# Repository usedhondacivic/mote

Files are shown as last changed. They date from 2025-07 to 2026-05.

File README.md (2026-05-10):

# Mote





A low cost and high confidence mobile robot.

## Motivation

Robotics is more fun with real hardware.

["Low cost"](https://www.robotshop.com/products/clearpath-robotics-turtlebot-4-mobile-robot) robots are prohibitively expensive for aspiring engineers.
We believe robotics should be affordable, enjoyable, and obtainable. So we made Mote.

## History

Mote is the spiritual successor of [the Little Red Rover project](https://github.com/little-red-rover).

For the past two years, Little Red Rover has been used to teach the Foundations of Robotics course at Cornell University.
Mote is the product of the many lessons learned during that effort.

## Contributing

Want to patch a bug, add a feature, or otherwise improve Mote?
Checkout [the contribution guide](https://empriselab.github.io/mote/advanced/contributing/contributing.html).

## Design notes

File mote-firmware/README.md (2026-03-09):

# mote-firmware

Embassy firmware for the RP2530 that runs mote.

## Build and Deploy

Requirements:
* [cargo](https://rustup.rs) (rust package manager)
* [just](https://just.systems/man/en/) (task runner)
* [probe-rs](https://probe.rs/docs/getting-started/installation/) (flasher / debugger)

From this folder, run

```
just deploy
```

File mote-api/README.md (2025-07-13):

# mote-messages

Message definitions that define the firmware <--> host driver interface

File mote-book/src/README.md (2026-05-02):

# Mote

A low cost and high confidence mobile robot for hands on robotics education.

## Highlights

* High rate LiDAR, IMU, and actuator position data
* Polished interfaces for ROS, ROS2, Python and Rust
* Wide cross platform support
* Completely open source, forever
* Assemble for just ~$100

Mote is supported by Cornell University's [EmPRISE Lab](https://empriselab.github.io/).

## Get Started

Want to build your own Mote? Check out [the hardware sourcing guide](./hardware-sourcing/acquire.md).

Have a Mote? Get started by [assembling your kit](./getting_started/kit-assembly.md).

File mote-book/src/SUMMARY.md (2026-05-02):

# Summary

[Home](README.md)

# Getting Started

- [Kit Assembly](./getting_started/kit-assembly.md)
- [Configuration](./getting_started/configuration.md)
- [Hello Mote](./getting_started/hello-world.md)

# Guides

- [Python]()
    - [Visualization]()
    - [Teleop]()

- [Rust]()
    - [Visualization]()
    - [Teleop]()

- [ROS Noetic (EOL)]()
    - [Visualization]()
    - [Teleop]()
    - [Nav2]()

- [ROS2]()
    - [Visualization]()
    - [Teleop]()
    - [Nav2]()

# Hardware Sourcing

- [Methods of Acquiring a Mote](./hardware-sourcing/acquire.md)
- [Bill of Materials](./hardware-sourcing/bom.md)
- [Ordering Circuit Boards](./hardware-sourcing/circuit-boards.md)
- [3D Printed Parts](./hardware-sourcing/printed.md)

# Advanced

- [Contributing](./advanced/contributing/contributing.md)
    - [Development Environment](./advanced/contributing/dev_env.md)
    - [Building, Testing, Running, and Releasing](./advanced/contributing/build_test_deploy.md)
    - [Hardware](./advanced/contributing/hardware.md)
# Misc

- [Project Philosophy]()
- [FAQs]()

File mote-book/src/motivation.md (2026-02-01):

# Motivation

## What?

Mote is an affordable and intuitive robot that makes it a joy to learn robotics.

## Why?

Robotics is more fun with real hardware.

Existing hardware solutions are prohibitively expensive for aspiring engineers and provide a frustrating development experience.
It doesn't have to be this way.

## How?

### Status Quo

Mobile robots (like Mote) have three core operations:
1. Collecting observations (reading sensor data)
2. Processing observations (computing odometry, localization, etc)
3. Responding to observations (generating actuator movement)

Traditionally, all three steps are run onboard the robot. 
This requires a real time processor (likely an microcontroller) for (1) and (3), paired with a single board computer (SBC) for (2).

The setup works alright, but relies on an expensive and power hungry SBC that tends to complicate system setup and encourage brittle and opaque configurations.
Can we do better?

### Mote's Approach

Mote forgoes an onboard SBC by wirelessly offloading data processing to an external base station.
The base station can be any computer, running any operating system, and is most often just the user's laptop.

Buy omiting the SBC Mote can get away with a miniscule power and computation budget, dropping the price and greating improving runtime.
Perfomance actually *improves* without the SBC, as even outdated laptops can outperform the average SBC.

## Where?

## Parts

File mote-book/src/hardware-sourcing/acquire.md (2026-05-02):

# Methods of Acquiring a Mote

Mote uses a custom circuit board that must be manufactured and assembled at a factory.
While PCBA has become remarkably affordable in recent years, setup fees make the cost per unit high for low scale runs (1 - 10 units).

If you would like to order a small number of robots please take a look on [the issue tracker](https://github.com/empriselab/mote-core/issues) and see if a group buy is being coordinated.
If you don't see a group buy posted, reach out to [a member of the Mote team](mailto:mmc323@cornell.edu) and we can help you start one.

If you would like to build many Motes you can start your own manufacturing run. Checkout [Ordering Circuit Boards](./circuit-boards.md) for a step by step guide on the process.
It's much easier than it sounds.

All other (non-3D printed) parts are commercially available through standard channels. See the [Bill of Materials page](./bom.md) for details.

The rest of the robot is 3D printed. The [3D Printed Parts page](./printed.md) provides guidance for producing these parts.

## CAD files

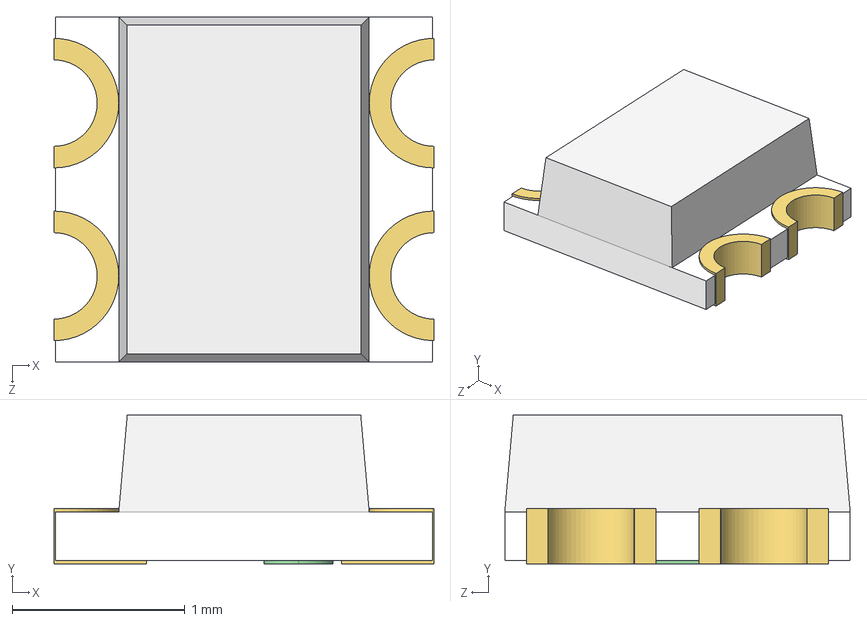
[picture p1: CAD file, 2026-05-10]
mote-hardware/models/WS2812-2020.STEP
2.20 x 0.86 x 2.00 mm

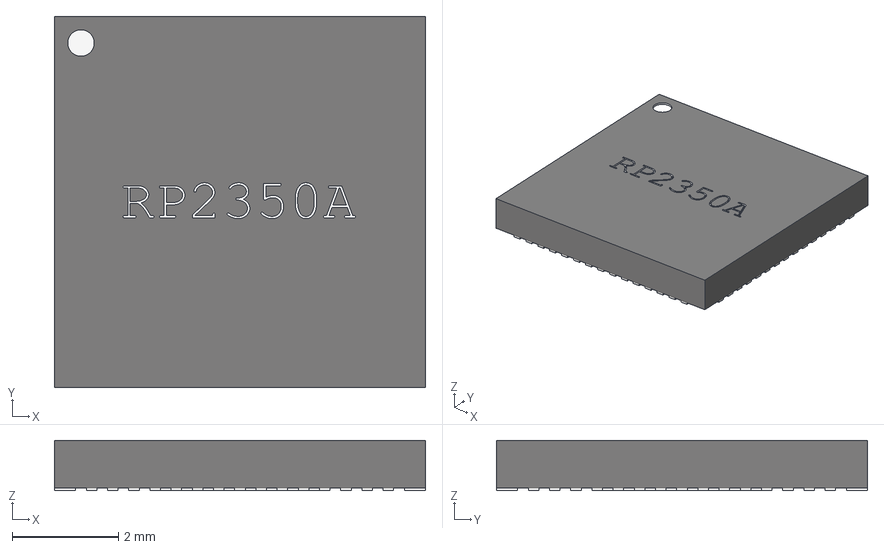
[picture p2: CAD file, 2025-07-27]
mote-hardware/RP2350_QFN60.step
7.00 x 7.00 x 0.95 mm

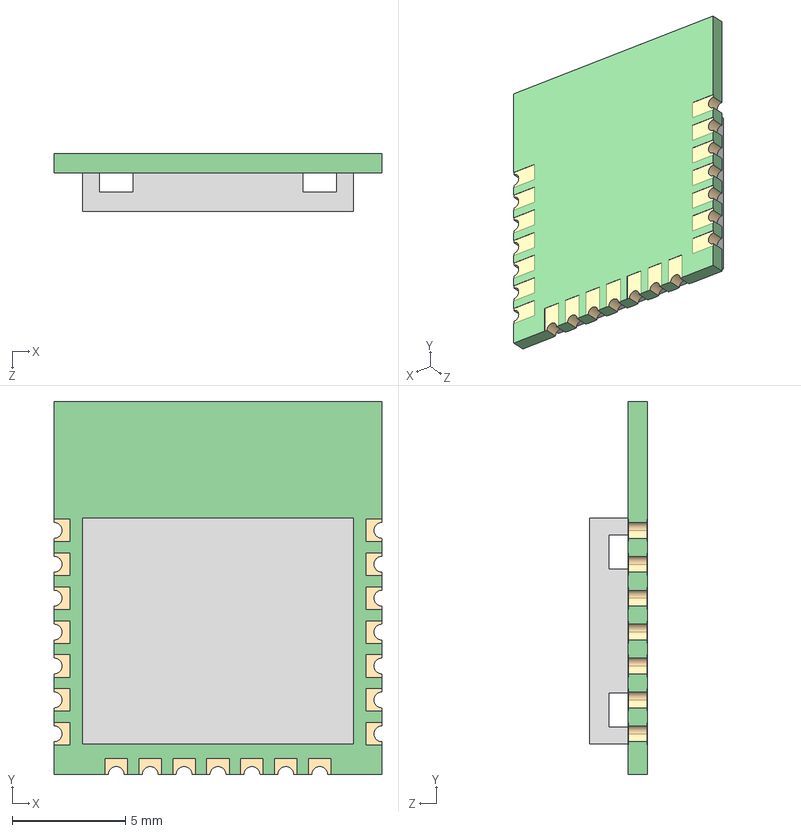
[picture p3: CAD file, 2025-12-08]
mote-hardware/models/rpi_rmc20452t.step
14.5 x 16.5 x 2.55 mm

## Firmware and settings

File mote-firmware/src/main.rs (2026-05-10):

#![no_std]
#![no_main]
// generic_const_exprs is intentionally used in the LiDAR driver
#![allow(incomplete_features)]
// Embassy tasks pass ownership of hardware resources as arguments
#![allow(clippy::too_many_arguments)]
// Used minimally in the LiDAR driver, still very unstable
#![feature(generic_const_exprs)]
// Embassy-isms
#![feature(impl_trait_in_assoc_type)]
#![allow(async_fn_in_trait)]

extern crate alloc;

use defmt::info;
use embassy_executor::{Executor, Spawner};
use embassy_rp::clocks::{ClockConfig, CoreVoltage, clk_sys_freq};
use embassy_rp::config::Config;
use embassy_rp::multicore::{Stack, spawn_core1};
use embedded_alloc::LlffHeap as Heap;
use static_cell::StaticCell;
use {defmt_rtt as _, panic_probe as _};

use crate::tasks::*;

mod flash_config;
mod helpers;
mod tasks;

#[global_allocator]
static HEAP: Heap = Heap::empty();

const HEAP_SIZE: usize = 100 * 1024;

// Program metadata for `picotool info`.
#[unsafe(link_section = ".bi_entries")]
#[used]
pub static PICOTOOL_ENTRIES: [embassy_rp::binary_info::EntryAddr; 4] = [
    embassy_rp::binary_info::rp_program_name!(c"Mote"),
    embassy_rp::binary_info::rp_program_description!(c"A low cost, high confidence robot for education"),
    embassy_rp::binary_info::rp_cargo_version!(),
    embassy_rp::binary_info::rp_program_build_attribute!(),
];

static mut CORE1_STACK: Stack<10000> = Stack::new();
static EXECUTOR0: StaticCell<Executor> = StaticCell::new();
static EXECUTOR1: StaticCell<Executor> = StaticCell::new();

#[cortex_m_rt::entry]
fn main() -> ! {
    // Set up for clock frequency of 200 MHz, setting all necessary defaults.
    let mut config = Config::new(ClockConfig::system_freq(200_000_000).unwrap());
    config.clocks.core_voltage = CoreVoltage::V1_15;

    let p = embassy_rp::init(config);
    let r = split_resources!(p);

    info!("System clock frequency: {} MHz", clk_sys_freq() / 1_000_000);

    // Init the allocator
    unsafe {
        embedded_alloc::init!(HEAP, HEAP_SIZE);
    }

    spawn_core1(
        p.CORE1,
        unsafe { &mut *core::ptr::addr_of_mut!(CORE1_STACK) },
        move || {
            let executor1 = EXECUTOR1.init(Executor::new());
            executor1.run(|spawner| {
                spawner.spawn(
                    core1_task(
                        spawner,
                        r.usb_serial,
                        r.status_led,
                        r.lidar_uart,
                        r.imu,
                        r.encoder_driver,
                        r.left_encoder,
                        r.right_encoder,
                        r.drv8833_resources,
                        r.usb_power_detection,
                    )
                    .unwrap(),
                )
            });
        },
    );

    let executor0 = EXECUTOR0.init(Executor::new());

    executor0.run(|spawner| spawner.spawn(core0_task(spawner, r.wifi, r.flash).unwrap()));
}

#[embassy_executor::task]
async fn core0_task(spawner: Spawner, r: Cyw43Resources, flash_r: FlashResources) {
    info!("Core 0 spawned");

    spawner.spawn(flash_manager::flash_manager_task(flash_r).unwrap());
    info!("Flash INIT complete");

    wifi::init(spawner, r).await;
    info!("Wifi INIT complete");
}

#[embassy_executor::task]
async fn core1_task(
    spawner: Spawner,
    usb_r: UsbSerialResources,
    status_led_r: StatusLedResources,
    lidar_r: RplidarC1Resources,
    imu_r: ImuResources,
    encoder_driver_r: EncoderDriverResources,
    left_encoder_r: LeftEncoderResources,
    right_encoder_r: RightEncoderResources,
    motor_driver_r: DRV8833Resources,
    usb_power_r: UsbPowerDetectionResources,
) {
    info!("Core 1 spawned");

    /* Initial configuration state is set in core0_task after flash init */
    status_led::init(spawner, status_led_r).await;
    info!("Status LEDs INIT complete");

    usb_serial::init(spawner, usb_r).await;
    info!("USB Serial INIT complete");

    power_gate::init(spawner, usb_power_r).await;
    info!("Power Gate INIT complete");

    lidar::init(spawner, lidar_r).await;
    info!("LiDAR INIT complete");

    imu::init(spawner, imu_r).await;
    info!("IMU INIT complete");

    drive_base::init(
        spawner,
        motor_driver_r,
        encoder_driver_r,
        left_encoder_r,
        right_encoder_r,
    )
    .await;
    info!("Drive base INIT complete");
}

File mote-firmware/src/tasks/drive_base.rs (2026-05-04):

use defmt::{error, info};
use embassy_executor::Spawner;
use embassy_futures::select::select4;
use embassy_rp::pio::{Instance, Pio};
use embassy_rp::pwm::SetDutyCycle;
use embassy_rp::{gpio, pwm};
use embassy_time::{Duration, Instant, Ticker, Timer};
use mote_api::messages::mote_to_host::{DriveBaseState, Message, WheelJointState};
use pid::Pid;

use crate::tasks::drive_base::encoder::PioEncoder;
use crate::tasks::drive_base::hbridge::PwmBridge;
use crate::tasks::wifi::{DATA_OFFLOAD_CHANNEL, MOTOR_COMMAND_CHANNEL};
use crate::tasks::{
    DRV8833Resources, EncoderDriverResources, Irqs, LeftEncoderResources, RightEncoderResources, power_gate,
};

mod encoder;
mod hbridge;

/// Number of encoder pulses recorded per rotation.
/// This is specific to each model of TT motor, right now we use:
/// https://category.yahboom.net/products/encoder-tt-motor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
/// We may want to make this a configurable value to support different motors.
const ENCODER_PULSES_PER_ROTATION: u16 = 630;
/// Stiction prevents commands lower than this % from causing motion.
const MOTOR_DEADBAND_PERCENT: u8 = 52;
/// PDI commands lower than this % are filtered to prevent chattering due to
/// gearbox hysteresis.
const CONTROL_DEADBAND_PERCENT: f32 = 2.;
/// ms per iteration of the PID control loop.
const PID_CONTROL_LOOP_PERIOD_MS: u64 = 20;
/// ms per joint state telemetry value.
const TELEMETRY_LOOP_PERIOD_MS: u64 = 100;
/// Seconds of not receiving a command before deactivating the drive base.
const WATCH_DOG_TIMEOUT: u64 = 1;

/// Convert encoder pulses into radians
fn encoder_pulses_to_rad(pulses: i32) -> f32 {
    (pulses as f32 / ENCODER_PULSES_PER_ROTATION as f32) * 2. * core::f32::consts::PI
}

/// Represents a motor with an hbridge driver and quadrature encoder.
struct Motor<'d, T: SetDutyCycle, P: Instance, const SM: usize> {
    bridge: PwmBridge<T>,
    pio_encoder: PioEncoder<'d, P, SM>,
    pid: Pid<f32>,

    encoder_value: i32,
    pub joint_state: WheelJointState,
}

impl<'d, T: SetDutyCycle, P: Instance, const SM: usize> Motor<'d, T, P, SM> {
    fn new(bridge: PwmBridge<T>, encoder: PioEncoder<'d, P, SM>) -> Self {
        let ouput_limit = 100. - MOTOR_DEADBAND_PERCENT as f32;
        let pid = *Pid::<f32>::new(0., ouput_limit).p(8.0, ouput_limit).i(2.0, ouput_limit);

        Self {
            bridge,
            pio_encoder: encoder,
            pid,
            encoder_value: 0,
            joint_state: WheelJointState {
                effort_percent: 0.0,
                velocity_rad_per_s: 0.0,
                postition_rad: 0.0,
            },
        }
    }

    /// Set the target velocity in radians/second
    fn set_setpoint_rad_per_s(&mut self, setpoint: f32) {
        self.pid.setpoint(setpoint);
    }

    /// Step the motor's PID loop, targeting the latest setpoint commanded by
    /// set_setpoint
    async fn step(&mut self, dt_ms: u64) {
        let dt = dt_ms as f32 / 1000.;

        // Calculate rotation delta as pulses per second
        let last_encoder_read = self.encoder_value;
        self.encoder_value = self.pio_encoder.read().await;
        let measurement = encoder_pulses_to_rad(self.encoder_value - last_encoder_read);

        // Get the PID output accounting for the motor deadband
        let control_output = self.pid.next_control_output(measurement / dt).output;
        let deadband_adjusted_output = if control_output > 0. {
            control_output + MOTOR_DEADBAND_PERCENT as f32
        } else {
            control_output - MOTOR_DEADBAND_PERCENT as f32
        };

        // If the command exceeds the control deadband, forward it to the hbridge with
        // the correct polarity
        if control_output > CONTROL_DEADBAND_PERCENT {
            self.bridge.forward(deadband_adjusted_output as u8).unwrap();
        } else if control_output < -CONTROL_DEADBAND_PERCENT {
            self.bridge.reverse(-deadband_adjusted_output as u8).unwrap();
        } else {
            self.bridge.stop().unwrap();
        }

        // Update the joint state
        self.joint_state.postition_rad = encoder_pulses_to_rad(self.encoder_value);
        self.joint_state.velocity_rad_per_s = measurement / dt;
        self.joint_state.effort_percent = deadband_adjusted_output;
    }
}

#[embassy_executor::task]
async fn motor_task(
    encoder_driver_r: EncoderDriverResources,
    left_encoder_r: LeftEncoderResources,
    right_encoder_r: RightEncoderResources,
    motor_driver_r: DRV8833Resources,
) {
    info!("Gating on 3A capable before starting drive base");
    power_gate::gate_3_amp().await;
    info!("Power supply is 3A capable");

    // Setup PWM
    let desired_freq_hz = 25_000;
    let clock_freq_hz = embassy_rp::clocks::clk_sys_freq();
    let divider = 16u8;
    let period = (clock_freq_hz / (desired_freq_hz * divider as u32)) as u16 - 1;
    let mut pwm_config = pwm::Config::default();
    pwm_config.top = period;
    pwm_config.divider = divider.into();

    // Setup PIO
    let Pio {
        common: mut encoder_common,
        sm0: encoder_sm0,
        sm1: encoder_sm1,
        ..
    } = Pio::new(encoder_driver_r.pio, Irqs);

    // Configure left wheel
    let left_encoder = PioEncoder::new(
        &mut encoder_common,
        encoder_sm0,
        left_encoder_r.phase_a,
        left_encoder_r.phase_b,
    );

    let left_pwm = pwm::Pwm::new_output_ab(
        motor_driver_r.left_pwm,
        motor_driver_r.left_a,
        motor_driver_r.left_b,
        pwm_config.clone(),
    );
    let (Some(left_a), Some(left_b)) = left_pwm.split() else {
        error!("Unable to init drive base PWM. Drive-base disabled.");
        return;
    };
    let left_pwm_bridge = PwmBridge::new(left_a, left_b, 0);
    let mut left_motor = Motor::new(left_pwm_bridge, left_encoder);

    // Configure right wheel
    let right_encoder = PioEncoder::new(
        &mut encoder_common,
        encoder_sm1,
        right_encoder_r.phase_a,
        right_encoder_r.phase_b,
    );

    let right_pwm = pwm::Pwm::new_output_ab(
        motor_driver_r.right_pwm,
        motor_driver_r.right_a,
        motor_driver_r.right_b,
        pwm_config.clone(),
    );
    let (Some(right_a), Some(right_b)) = right_pwm.split() else {
        error!("Unable to init drive base PWM. Drive-base disabled.");
        return;
    };
    let right_pwm_bridge = PwmBridge::new(right_a, right_b, 0);
    let mut right_motor = Motor::new(right_pwm_bridge, right_encoder);

    // Init sleep pin
    let mut sleep = gpio::Output::new(motor_driver_r.sleep, gpio::Level::High);

    // PID, telem and watchdog timers
    let mut pid_ticker = Ticker::every(Duration::from_millis(PID_CONTROL_LOOP_PERIOD_MS));
    let mut telemetry_ticker = Ticker::every(Duration::from_millis(TELEMETRY_LOOP_PERIOD_MS));
    let mut watchdog_deadline = Instant::now() + Duration::from_secs(WATCH_DOG_TIMEOUT);
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

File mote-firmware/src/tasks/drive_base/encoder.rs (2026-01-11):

// From: https://github.com/embassy-rs/embassy/blob/main/examples/rp235x/src/bin/pio_rotary_encoder_rxf.rs

use embassy_rp::gpio::Pull;
use embassy_rp::pio::program::pio_asm;
use embassy_rp::pio::{Common, Config, FifoJoin, Instance, PioPin, ShiftDirection, StateMachine};
use embassy_rp::{Peri, pio};
use fixed::traits::ToFixed;

pub struct PioEncoder<'d, T: Instance, const SM: usize> {
    sm: StateMachine<'d, T, SM>,
}

impl<'d, T: Instance, const SM: usize> PioEncoder<'d, T, SM> {
    pub fn new(
        pio: &mut Common<'d, T>,
        mut sm: StateMachine<'d, T, SM>,
        pin_a: Peri<'d, impl PioPin>,
        pin_b: Peri<'d, impl PioPin>,
    ) -> Self {
        let mut pin_a = pio.make_pio_pin(pin_a);
        let mut pin_b = pio.make_pio_pin(pin_b);
        pin_a.set_pull(Pull::Up);
        pin_b.set_pull(Pull::Up);

        sm.set_pin_dirs(pio::Direction::In, &[&pin_a, &pin_b]);

        let prg = pio_asm!(
            "start:"
            // encoder count is stored in X
            "mov isr, x"
            // and then moved to the RX FIFO register
            "mov rxfifo[0], isr"

            // wait for encoder transition
            "wait 1 pin 1"
            "wait 0 pin 1"

            "set y, 0"
            "mov y, pins[1]"

            // update X depending on pin 1
            "jmp !y decr"

            // this is just a clever way of doing x++
            "mov x, ~x"
            "jmp x--, incr"
            "incr:"
            "mov x, ~x"
            "jmp start"

            // and this is x--
            "decr:"
            "jmp x--, start"
        );

        let mut cfg = Config::default();
        cfg.set_in_pins(&[&pin_a, &pin_b]);
        cfg.fifo_join = FifoJoin::RxAsStatus;
        cfg.shift_in.direction = ShiftDirection::Left;
        cfg.clock_divider = 0x0200.to_fixed();
        cfg.use_program(&pio.load_program(&prg.program), &[]);
        sm.set_config(&cfg);

        sm.set_enable(true);
        Self { sm }
    }

    pub async fn read(&mut self) -> i32 {
        self.sm.get_rxf_entry(0) as i32
    }
}

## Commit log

2025-06-16 First pass at RPLidar driver
2025-07-13 Outline impl for mote-messages, mote-host-driver
2025-07-20 Lidar streaming, rerun viz
2025-07-27 Init mote hardware with RP2350 minimal design
    [RP2350_QFN60.step, mote-hardware.kicad_pcb, mote-hardware.kicad_sch]
2025-09-07 Move mote comms driver to mote-sansio-driver
2025-09-08 WASM wrapper for sansio driver in configuration page
2025-09-14 Switch to COBS, implement webserial send and recv logic
2025-09-25 Update sansio driver for fragmented packets, use driver in firmware
2025-10-06 mDNS discovery, dual core, robustness updates, rerun demo fixed
    [lib.rs, lidar.rs, main.rs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]
2025-10-08 Patch configuration page for new io driver api
2025-10-11 Clean up wifi driver
2025-10-14 Sansio bugfix, uid update and network refresh for config page
    [lib.rs]
2025-10-19 Fix bug in sansio driver
    [lib.rs, main.rs, wifi.rs]
2025-11-02 Decompose wifi driver into multiple files
2025-11-02 Refactor LiDAR driver
2025-12-08 First pass at RP2350 schematic
    [imu.kicad_sch, mote-hardware.kicad_sch, motor.kicad_sch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]
2025-12-14 Implement motor, power, imu, status LED schematics
    [imu.kicad_sch, mote-hardware.kicad_sch, motor.kicad_sch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]
2025-12-30 Update resource assigment to support imu, encoders, status leds
2025-12-31 First draft schematic complete
    [imu.kicad_sch, mote-hardware.kicad_sch, motor.kicad_sch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]
2025-12-31 Footprint assignments
    [motor.kicad_sch, power.kicad_sch, rp2354.kicad_sch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]
2025-12-31 Start of PCB layout
    [mote-hardware.kicad_pcb]
2026-01-11 Fix skipped encoder edges from low PIO clockrate
    [drive_base.rs, encoder.rs]
2026-01-11 Implement DRV8833 driver
2026-01-12 Add PID control to drive base
2026-01-29 Add power gate for 1.5A and 3.0A capable
2026-02-08 WIP transition sansio driver into mote-messages, expose python and wasm apis
2026-02-23 Rework IO driver, add just rules, restructure web, remove OOD crates
    [lib.rs, lidar.rs, main.rs]
2026-02-24 Fix errors with CI
    [lib.rs]
2026-02-25 Add lint just recipes, fix clippy errors in mote-api
    [lib.rs]
2026-02-25 Fix clippy errors in mote-firmware
    [drive_base.rs, hbridge.rs, lidar.rs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]
2026-02-26 Fix issues with mote-link on configuration page (#2)
    Fixes regression on the configuration page where serial byte arrays were
    not being properly parsed from js.
    [lib.rs]
2026-02-26 Add BIT for power (#3)
    Add BIT (built in test) for the power gating task. BIT diagnostics show
    on the configuration page to help debug power issues.
    [power_gate.rs, tasks.rs]
2026-02-26 Patch BIT for power gating (#10)
2026-03-09 Restructure FFI, generate schema files and type info (#15)
    Various structural changes and bug fixes surrounding mote-ffi and python
    interop
    [lib.rs, main.rs]
2026-03-10 Fix mote-firmware clippy violations (#1)
    mote-firmware contains clippy violations that prevent enabling linting
    on that crate in CI. Fix the violations and update the mote-firmware
    justfile to include the lint recipe in CI.
    [drive_base.rs, hbridge.rs, main.rs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]
2026-03-16 Fix rerun rs example, finish mote-ffi python bindings (#21)
    Drive by fixes for the rust example in mote-api. Implement a Python
    rerun example using the json ffi implementation in mote-ffi. Add test
    coverage.
    [lib.rs]
2026-03-17 Update mote configuration to use type checking (#27)
    Add type checking of mote-api types, drive by fix for bug where first
    UART message was ignored due to startup junk in buffer.
    [main.rs]
2026-03-21 FFI release infra (#28)
    Implements release rules / workflows for the FFI library. Python wheel
    is built using manylinux and the C static library uses cargo-zigbuild to
    lock the glibc library version for wide compatibility. MacOS releases
    are also supported via a runner matrix.
2026-04-01 Get pcb ready for first prototype order (#31)
    [imu.kicad_sch, mote-hardware.kicad_pcb, motor.kicad_sch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]
2026-04-01 Add hardware release CI workflow, hardware check CI workflow (#33)
    [mote-hardware.kibot.yaml, mote-hardware.kicad_pcb, motor.kicad_sch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]
2026-04-02 Hardware v0.0.0 order (#36)
    [imu.kicad_sch, mote-hardware.kicad_pcb, motor.kicad_sch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]
2026-04-12 Implement motor commands, wheel telemetry (#38)
    Implements the motor control / data offload pipeline + updates the rerun
    example to display the data.
    Drive by fixes:
    * DRC check was using a top level filter which was causing the action to
    hang on PR
    * Add IMU message types to mote-api and related tooling.
    [drive_base.rs, lib.rs, lidar.rs]
2026-04-15 Flash driver (#42)
    Add a flash driver to persist network creds and UID information in flash
    between reboots.
    [lib.rs, main.rs]
2026-04-16 Address WiFi stability issues (#44)
    WiFi init was being flaky and occasionally hanging. Seems like something
    related to flashing the CYW43 firmware and when I touched flash for the
    flash driver.
    [main.rs, wifi.rs]
2026-04-19 fixed rejoining different network by leaving current network first (#46)
2026-04-23 Bump embassy versions (#49)
    The cyw driver was sporadically failing to initialize, essentially
    bricking the robot. The root cause was unclear so I tried bumping the
    versions of all embassy crates to the latest releases. This seems to
    have fixed the issue.
    Also added variable debugging output levels
    ```
    just deploy # info level prints
    just debug # debug level prints
    just trace # trace level prints
    ```
    [drive_base.rs, lidar.rs, main.rs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]
2026-04-23 Auto icmp + power gate fixes (#50)
    Replace icmp flag that got removed during package update. Move power
    gates into tasks so they don't block the executor task. Update power
    gate voltage ranges to accept off spec voltages
    [drive_base.rs, lidar.rs, main.rs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]
2026-04-26 Imu driver (#41)
2026-05-04 Update pulses per rotation to correct value, retune PID (#55)
    [drive_base.rs]
2026-05-10 Hardware v0.1.0 updates (#52)
    Addresses errata / improvements identified in
    https://github.com/empriselab/mote-core/issues/37
    ---------
    [WS2812-2020.STEP, imu.kicad_sch, mote-hardware.kibot.yaml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]
2026-05-10 7 add neopixel status led driver (#47)
    Adds status leds to indicate configuration state of power gate, wifi,
    and sensors (imu/lidar)
